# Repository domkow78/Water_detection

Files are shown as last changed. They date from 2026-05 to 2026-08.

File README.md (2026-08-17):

# Water Detection

Repozytorium zawiera projekt systemu detekcji obecności magnesu i sterowania przekaźnikami dla różnych typów czujników wykorzystywanych w układzie wodnym.

## Cel projektu

Głównym celem jest monitorowanie stanu czujników, interpretacja sygnałów z wejść analogowych oraz sterowanie przekaźnikami w zależności od wykrycia obecności magnesu lub zmiany poziomu cieczy.

## Zawartość repozytorium

### Dokumentacja
- [APS11450_Program_Description.md](APS11450_Program_Description.md) — opis działania programu dla czujnika APS11450.
- [TLE4946_Program_Description.md](TLE4946_Program_Description.md) — opis działania programu dla czujnika TLE4946.
- [TMAG5124_Program_Description.md](TMAG5124_Program_Description.md) — opis działania programu dla czujnika TMAG5124B.
- [ReedSwitch_Program_Description.md](ReedSwitch_Program_Description.md) — opis działania programu dla czujnika Reed Switch.
- [APS11450.md](APS11450.md), [TLE4946.md](TLE4946.md), [TMAG5124B.md](TMAG5124B.md) — dokumentacja techniczna sensorów.

### Katalog src
W katalogu [src](src) znajdują się programy Arduino dla poszczególnych czujników:
- [src/Detector_APS11450](src/Detector_APS11450)
- [src/Detector_TLE4946](src/Detector_TLE4946)
- [src/Detector_TMAG5124](src/Detector_TMAG5124)
- [src/Detector_ReedSwitch](src/Detector_ReedSwitch)

Każdy program realizuje własną logikę detekcji i sterowania, dostosowaną do konkretnego typu czujnika.

### Katalog doc
W katalogu [doc](doc) znajduje się dokumentacja projektowa, modele 3D, schematy i pliki PCB związane z konstrukcją urządzenia.

### Katalog tests
Katalog [tests](tests) jest przeznaczony na testy i sprawdzenia funkcjonalne projektu.

## Wspierane typy czujników

- APS11450 — czujnik Halla używany do detekcji poziomu cieczy z diagnostyką.
- TLE4946 — czujnik Halla typu latch.
- TMAG5124B — czujnik prądowy z detekcją obecności magnesu.
- Reed Switch — czujnik binarny z połączeniem typu NO/NC zależnym od obecności magnesu.

## Główne funkcje systemu

- odczyt ADC z wejść czujników,
- konwersja sygnału na napięcie i prawidłową interpretację,
- histereza i filtracja stanów przejściowych,
- sterowanie przekaźnikami,
- logowanie danych przez UART,
- wizualizacja stanu na wyświetlaczu OLED.

## Narzędzia i platforma

Projekt jest realizowany w środowisku Arduino dla mikrokontrolerów AVR, z wykorzystaniem:
- biblioteki Arduino Core,
- wyświetlacza OLED SSD1306,
- obsługi watchdoga i ADC,
- przekaźników sterujących pracą układu.

## Krótka instrukcja

1. Otwórz odpowiedni plik programu z katalogu [src](src).
2. Wgraj skrypt na mikrokontroler.
3. Sprawdź działanie za pomocą monitora szeregowego i wyświetlacza OLED.
4. W razie potrzeby korzystaj z opisów w dokumentacji programowej.

## Uwagi

Repozytorium zawiera wersje projektowe dla różnych czujników i różnych podejść do detekcji, dlatego ważne jest dobieranie odpowiedniego programu do konkretnych komponentów zastosowanych w układzie.

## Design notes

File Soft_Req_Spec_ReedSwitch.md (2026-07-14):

# Sterownik poziomu wody oparty o kontaktrony (Reed Switch)

_Specyfikacja funkcjonalna_

## 1. Cel projektu

Celem projektu jest realizacja układu pomiaru poziomu cieczy przy użyciu trzech kontaktronów oraz pływaka z magnesem.

Dla zewnętrznego sterownika aplikacja ma zachowywać się identycznie jak klasyczny układ trzech elektrod zanurzeniowych.

---

## 2. Architektura

```text
Reed Switch x3
	│
	▼
Sensor Manager
	│
	▼
Level Resolver
	│
	▼
Relay Manager
	│
	▼
Sterownik zewnętrzny
```

### Sensor Manager

Odpowiada wyłącznie za warstwę sprzętową:

- odczyt wejść LOW/HIGH/SAFETY,
- podstawową filtrację drgań styków (debounce),
- publikację aktualnych stanów wejść.

Wyjście:

```text
SensorState
{
    low
    high
    safety
}
```

Sensor Manager nigdy nie interpretuje poziomu cieczy.

---

### Level Resolver

Jedyny moduł posiadający pamięć stanu.

Odpowiada za:

- określenie poziomu,
- inicjalizację po restarcie,
- filtrowanie stanów przejściowych,
- wykrywanie kierunku ruchu pływaka,
- emulację elektrod.

---

### Relay Manager

Wyłącznie mapuje poziom logiczny na wyjścia przekaźników.

---

## 3. Poziomy systemu

| Stan | R1 | R2 | R3 |
| --- | --- | --- | --- |
| EMPTY | 0 | 0 | 0 |
| LEVEL1 | 1 | 0 | 0 |
| LEVEL2 | 1 | 1 | 0 |
| LEVEL3 | 1 | 1 | 1 |

---

## 4. Wirtualne elektrody

| Poziom | E1 | E2 | E3 |
| --- | --- | --- | --- |
| EMPTY | 0 | 0 | 0 |
| LEVEL1 | 1 | 0 | 0 |
| LEVEL2 | 1 | 1 | 0 |
| LEVEL3 | 1 | 1 | 1 |

Relay Manager korzysta wyłącznie z E1-E3.

---

## 5. Automat stanów

```text
UNKNOWN
   │
   ▼
EMPTY <-> LEVEL1 <-> LEVEL2 <-> LEVEL3
```

Zmiany stanu są możliwe wyłącznie między sąsiednimi poziomami.

---

## 6. Restart

Po restarcie:

1. Sensor Manager rozpoczyna odczyt wejść i debounce.
2. Przez określony czas zbierane są próbki stanu wejść.
3. Level Resolver wybiera najbardziej prawdopodobny poziom startowy.
4. Aktualizowane są E1-E3.
5. Relay Manager ustawia przekaźniki zgodnie z wybranym poziomem.

Do czasu zakończenia inicjalizacji zaleca się utrzymanie poprzedniego stanu wyjść.

---

## 7. Stany przejściowe

Podczas ruchu pływaka mogą występować chwilowe kombinacje stanów wejść, które nie odpowiadają stabilnemu poziomowi.

Takie stany nie powodują natychmiastowej zmiany poziomu.

Level Resolver:

- wykorzystuje poprzedni poziom,
- oczekuje stabilizacji wejść przez zdefiniowany czas,
- dopiero wtedy zatwierdza nowy poziom.

---

## 8. Tabela przejść

| Aktualny stan | Potwierdzone zdarzenie | Nowy stan | Akcja |
| --- | --- | --- | --- |
| UNKNOWN | INIT_COMPLETE + EMPTY | EMPTY | R=000 |
| UNKNOWN | INIT_COMPLETE + LEVEL1 | LEVEL1 | R=100 |
| UNKNOWN | INIT_COMPLETE + LEVEL2 | LEVEL2 | R=110 |
| UNKNOWN | INIT_COMPLETE + LEVEL3 | LEVEL3 | R=111 |
| EMPTY | LEVEL1 potwierdzony | LEVEL1 | Włącz R1 |
| LEVEL1 | LEVEL2 potwierdzony | LEVEL2 | Włącz R2 |
| LEVEL2 | LEVEL3 potwierdzony | LEVEL3 | Włącz R3 |
| LEVEL3 | LEVEL2 potwierdzony | LEVEL2 | Wyłącz R3 |
| LEVEL2 | LEVEL1 potwierdzony | LEVEL1 | Wyłącz R2 |
| LEVEL1 | EMPTY potwierdzony | EMPTY | Wyłącz R1 |

---

## 9. Kombinacje niestabilne

Surowe odczyty:

```text
010
001
101
011
```

traktowane są jako stany przejściowe i nie powodują bezpośredniej zmiany poziomu.

Ich interpretacja zależy wyłącznie od historii stanów oraz czasu stabilizacji.

---

## 10. Zasady implementacyjne

- Przekaźniki nigdy nie są sterowane bezpośrednio z kontaktronów.
- Jedynym źródłem informacji o poziomie jest Level Resolver.
- Sensor Manager nie zawiera logiki procesu.
- Relay Manager nie odczytuje czujników.
- Wszystkie zmiany poziomu powinny być logowane.
- System musi być odporny na restart oraz chwilowe stany przejściowe.

---

## 11. Skalowalność

Dodanie kolejnych poziomów wymaga:

- dodania czujnika,
- rozszerzenia konfiguracji Level Resolver,
- rozszerzenia tabeli przejść.

Pozostałe moduły pozostają bez zmian.

---

## 12. Główna zasada projektowa

Kontaktrony nie sterują bezpośrednio przekaźnikami.

Kontaktrony dostarczają wyłącznie sygnały wejściowe.

Level Resolver przekształca sygnały w logiczny stan poziomu.

Relay Manager generuje sygnały identyczne z klasycznym układem elektrod zanurzeniowych.

Dzięki temu aplikacja zachowuje zgodność funkcjonalną z układem elektrodowym i zapewnia stabilną pracę podczas ruchu pływaka oraz po restarcie.

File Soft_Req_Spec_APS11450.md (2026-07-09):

# Sterownik poziomu wody oparty o APS11450

_Specyfikacja funkcjonalna_

## 1. Cel projektu

Celem projektu jest zastąpienie klasycznego układu elektrodowego układem wykorzystującym trzy czujniki Halla APS11450 oraz pływak z magnesem.

Dla zewnętrznego sterownika aplikacja ma zachowywać się identycznie jak trzy elektrody zanurzeniowe.

---

## 2. Architektura

```text
APS11450 x3
     │
     ▼
Sensor Manager
     │
     ▼
Level Resolver
     │
     ▼
Relay Manager
     │
     ▼
Sterownik zewnętrzny
```

### Sensor Manager

Odpowiada wyłącznie za sprzęt:

- odczyt wejść LOW/HIGH/SAFETY,
- odczyt ADC (diagnostyka APS11450),
- wykrywanie Internal Fault,
- wykrywanie External Fault.

Wyjście:

```text
SensorState
{
    low
    high
    safety
    lowFault
    highFault
    safetyFault
}
```

Nigdy nie interpretuje poziomu cieczy.

---

### Level Resolver

Jedyny moduł posiadający pamięć stanu.

Odpowiada za:

- określenie poziomu,
- inicjalizację po restarcie,
- filtrowanie stanów przejściowych,
- wykrywanie kierunku ruchu,
- diagnostykę logiczną,
- emulację elektrod.

---

### Relay Manager

Wyłącznie mapuje poziom na wyjścia przekaźników.

---

## 3. Poziomy systemu

| Stan | R1 | R2 | R3 |
| --- | --- | --- | --- |
| EMPTY | 0 | 0 | 0 |
| LEVEL1 | 1 | 0 | 0 |
| LEVEL2 | 1 | 1 | 0 |
| LEVEL3 | 1 | 1 | 1 |
| FAULT | zgodnie z konfiguracją bezpieczeństwa | | |

---

## 4. Wirtualne elektrody

| Poziom | E1 | E2 | E3 |
| --- | --- | --- | --- |
| EMPTY | 0 | 0 | 0 |
| LEVEL1 | 1 | 0 | 0 |
| LEVEL2 | 1 | 1 | 0 |
| LEVEL3 | 1 | 1 | 1 |

Relay Manager korzysta wyłącznie z E1-E3.

---

## 5. Automat stanów

```text
UNKNOWN
   │
   ▼
EMPTY <-> LEVEL1 <-> LEVEL2 <-> LEVEL3

Każdy stan -> FAULT
FAULT -> UNKNOWN
```

---

## 6. Restart

Po restarcie:

1. Sensor Manager wykonuje diagnostykę.
2. Przez określony czas zbierane są próbki.
3. Level Resolver wybiera najbardziej prawdopodobny poziom.
4. Aktualizowane są E1-E3.
5. Relay Manager ustawia przekaźniki.

Do czasu zakończenia inicjalizacji zaleca się utrzymanie poprzedniego stanu wyjść.

---

## 7. Stany przejściowe

Podczas przejazdu magnesu mogą pojawić się kombinacje nieodpowiadające rzeczywistemu poziomowi.

Nie powodują one natychmiastowej zmiany poziomu.

Level Resolver:

- wykorzystuje poprzedni poziom,
- oczekuje stabilizacji,
- dopiero wtedy zatwierdza nowy poziom.

---

## 8. Diagnostyka

### Sprzętowa

- Internal Fault APS11450
- External Fault APS11450
- błędy ADC

### Logiczna

- niedozwolona sekwencja,
- przeskok poziomu,
- zbyt długi stan przejściowy,
- utrata synchronizacji,
- niespójne stany.

---

## 9. Tabela przejść

| Aktualny stan | Potwierdzone zdarzenie | Nowy stan | Akcja |
| --- | --- | --- | --- |
| UNKNOWN | INIT_COMPLETE + EMPTY | EMPTY | R=000 |
| UNKNOWN | INIT_COMPLETE + LEVEL1 | LEVEL1 | R=100 |
| UNKNOWN | INIT_COMPLETE + LEVEL2 | LEVEL2 | R=110 |
| UNKNOWN | INIT_COMPLETE + LEVEL3 | LEVEL3 | R=111 |
| EMPTY | LEVEL1 potwierdzony | LEVEL1 | Włącz R1 |
| LEVEL1 | LEVEL2 potwierdzony | LEVEL2 | Włącz R2 |
| LEVEL2 | LEVEL3 potwierdzony | LEVEL3 | Włącz R3 |
| LEVEL3 | LEVEL2 potwierdzony | LEVEL2 | Wyłącz R3 |
| LEVEL2 | LEVEL1 potwierdzony | LEVEL1 | Wyłącz R2 |
| LEVEL1 | EMPTY potwierdzony | EMPTY | Wyłącz R1 |
| Dowolny | Internal/External Fault | FAULT | Alarm |

---

## 10. Niedozwolone kombinacje

Surowe odczyty:

```text
010
001
101
011
```

nie powodują automatycznie zmiany poziomu.

Mogą oznaczać:

- ruch pływaka,
- restart,
- uszkodzenie czujnika,
- uszkodzenie okablowania.

Ich interpretacja zależy od historii i diagnostyki.

---

## 11. Zasady implementacyjne

- Przekaźniki nigdy nie są sterowane bezpośrednio z czujników.
- Jedynym źródłem informacji o poziomie jest Level Resolver.
- Sensor Manager nie zna logiki procesu.
- Relay Manager nie odczytuje czujników.
- Wszystkie zmiany poziomu są logowane.
- Wszystkie błędy posiadają własny kod diagnostyczny.
- System musi być odporny na restart oraz stany przejściowe.

---

## 12. Skalowalność

Dodanie kolejnych poziomów wymaga:

- dodania czujnika,
- rozszerzenia konfiguracji Level Resolver,
- rozszerzenia tabeli przejść.

Pozostałe moduły pozostają bez zmian.

---

## 13. Główna zasada projektowa

Czujniki APS11450 nie sterują przekaźnikami.

Czujniki dostarczają wyłącznie dane pomiarowe.

Level Resolver przekształca dane w logiczny stan poziomu.

Relay Manager generuje sygnały identyczne z klasycznym układem elektrodowym.

Dzięki temu aplikacja jest odporna na:

- przejazd magnesu pomiędzy czujnikami,
- restart urządzenia,
- błędy pojedynczych czujników,
- zmianę technologii czujników w przyszłości.

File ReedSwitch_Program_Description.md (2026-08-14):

# Opis działania programu dla Reed Switch

## 1. Cel programu

Program sprawdza trzy kanały Reed Switch:
- `LOW`
- `HIGH`
- `SAFE`

Dla każdego kanału odczytuje stan wejścia i steruje odpowiadającym mu przekaźnikiem.

Zasada działania jest prosta i binarna:
- reed zwarty przez magnes = stan aktywny
- reed rozwarty = stan nieaktywny
- przekaźnik odzwierciedla stan danego czujnika

Nie ma tutaj mapowania poziomu na inny stan, nie ma automatu stanu i nie ma rozbudowanej diagnostyki błędów.

---

## 2. Wejścia i wyjścia

### 2.1. Wejścia

Wszystkie wejścia są ustawione jako `INPUT_PULLUP`:
- `REED_LOW_PIN = 2`
- `REED_HIGH_PIN = 3`
- `REED_SAFE_PIN = 4`

Dla takiego podłączenia:
- stan aktywny = `LOW` (kontakt zwarty, magnes w pobliżu, wejście podłączone do GND)
- stan nieaktywny = `HIGH` (kontakt rozwarty, wejście podciągnięte do VCC)

### 2.2. Wyjścia

Przekaźniki są sterowane osobno dla każdego kanału:
- `RELAY_LOW_PIN = A0`
- `RELAY_HIGH_PIN = A1`
- `RELAY_SAFE_PIN = A2`

Każdy przekaźnik ma odpowiadać stanowi swojego reed switcha.

---

## 3. Logika działania

Program odczytuje napięcie na każdym wejściu Reed Switch i interpretuje je jako dwa stany:

- napięcie bliskie 0 V → reed zwarty → przekaźnik ON
- napięcie bliskie VCC → reed rozwarty → przekaźnik OFF

To jest czysta logika binarna. Każdy kanał działa niezależnie.

---

## 4. Histereza

Aby uniknąć migania przy przejściach, program stosuje progi histerezy:

- `REED_ACTIVE_V = 1.0 V`
- `REED_RELEASED_V = 2.5 V`

Dla danego kanału:
- jeżeli stan jest nieaktywny i napięcie spadnie poniżej 1,0 V, kanał przechodzi do aktywnego,
- jeżeli stan jest aktywny i napięcie wzrośnie powyżej 2,5 V, kanał przechodzi do nieaktywnego,
- w pozostałych przypadkach stan zostaje bez zmian.

Dzięki temu krótkie oscylacje napięcia nie powodują niepotrzebnych przełączeń przekaźników.

---

## 5. Odczyt analogowy i VCC

Program mierzy napięcie na wejściach analogowo, ale robi to wyłącznie po to, aby odczytać rzeczywisty poziom sygnału i porównać go z progami histerezy. Nie ma osobnej funkcji diagnostycznej typu `OPEN`/`SHORT`.

Wartość `Vcc` jest odczytywana przez funkcję `readVcc()` i wykorzystywana do przeliczenia surowego odczytu ADC na napięcie w woltoch.

W praktyce oznacza to, że program ma dane do logowania i wizualizacji, ale nie rozpoznaje specjalnych stanów awarii, ponieważ czujnik Reed w tym układzie ma tylko dwa sensowne stany: zamknięty lub rozwarty.

---

## 6. Co dzieje się w `setup()`

W funkcji `setup()` program:
1. inicjalizuje port szeregowy,
2. ustawia wejścia Reed Switch jako `INPUT_PULLUP`,
3. ustawia wszystkie przekaźniki jako `OUTPUT`,
4. wyłącza przekaźniki na starcie,
5. inicjalizuje OLED,
6. odczytuje napięcie zasilania `Vcc`,
7. odczytuje początkowe stany wejść,
8. ustawia przekaźniki zgodnie z aktualnym stanem każdego kanału,
9. uruchamia watchdog.

---

## 7. Co dzieje się w `loop()`

W każdej iteracji programu:
1. odczytywane są wartości ADC dla `LOW`, `HIGH` i `SAFE`,
2. sygnały są zamieniane na napięcie w woltoch,
3. stosowana jest histereza dla każdego kanału,
4. przekaźniki otrzymują stan zgodny z wejściem,
5. dane są wysyłane do `Serial Monitor` i ekranu OLED.

---

## 8. Podsumowanie

Program dla Reed Switch działa w modelu 3 niezależnych kanałów binarnych:

- `LOW`: reed zwarty → LOW → przekaźnik ON
- `HIGH`: reed zwarty → LOW → przekaźnik ON
- `SAFE`: reed zwarty → LOW → przekaźnik ON

Przy rozwartym kontakcie:

- `HIGH`/`LOW`/`SAFE` = `HIGH` → przekaźnik OFF

W tym układzie największe znaczenie ma poprawna interpretacja napięcia i histereza. Nie ma rozbudowanej diagnostyki, bo czujnik ma tylko 2 realne stany logiczne: zamknięty i rozwarty.

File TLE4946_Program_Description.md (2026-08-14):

# Opis działania programu dla TLE4946

## 1. Cel programu

Program monitoruje trzy kanały czujników TLE4946 i na ich podstawie steruje trzema przekaźnikami. Każdy kanał jest odczytywany jako napięcie analogowe pochodzące z czujnika Halla, a następnie analizowany przez program z wykorzystaniem progów histerezy.

Głównym celem jest wykrywanie zmiany stanu czujnika w zależności od poziomu pola magnetycznego i utrzymanie stabilnych stanów logicznych w obecności zakłóceń, niewielkich zmian napięcia oraz szumu pomiarowego.

---

## 2. Założenia projektowe

### 2.1. Obwód pomiarowy

Każdy czujnik TLE4946 jest podłączony do wejścia ADC mikrokontrolera:
- HALL_LOW_PIN = A3
- HALL_HIGH_PIN = A6
- HALL_SAFE_PIN = A7

Napięcie z czujnika jest mierzone względem aktualnego napięcia zasilania układu.

### 2.2. Przekaźniki

Sterowanie przekaźnikami odbywa się poprzez wyjścia cyfrowe:
- RELAY_LOW_PIN = A0
- RELAY_HIGH_PIN = A1
- RELAY_SAFE_PIN = A2

Przekaźniki są aktywowane lub wyłączane na podstawie stanu odczytu z odpowiedniego czujnika.

---

## 3. Odczyt z ADC i uśrednianie

Każdy kanał odczytywany jest z wejścia ADC mikrokontrolera. W celu ograniczenia wpływu szumu i chwilowych niestabilności sygnału program wykonuje odczyty stabilizowane.

W praktyce funkcja `readADCStable()` działa w następujący sposób:
1. wykonuje pierwszy pomiar dla danego wejścia
2. odczekuje krótko (20 µs)
3. wykonuje kolejny pomiar
4. zwraca wartość z drugiego odczytu

To pozwala zmniejszyć błędy wynikające z nieustalonego stanu wejścia ADC lub krótkotrwałych zakłóceń.

Po odczycie wartość ADC jest zamieniana na napięcie:

V = (ADC / 1023) × VCC

Dzięki temu napięcia z czujników są skalowane do rzeczywistego napięcia zasilania systemu, a nie przyjmowane na sztywno jako 5 V.

Dodatkowo w tej wersji program wykonuje średniowanie z 8 próbek dla każdego kanału, co zwiększa odporność na drobne fluktuacje sygnału.

---

## 4. Weryfikacja VCC

Program mierzy napięcie zasilania mikrokontrolera w funkcji `readVcc()`. Jest to ważny element, ponieważ sygnał z czujnika musi być przeliczony względem aktualnego VCC.

Wewnętrzny mechanizm AVR ustawia wejście ADC do pracy z referencją wewnętrzną, po czym odczytuje wynik. Na podstawie tego wyniku obliczana jest wartość zasilania w milivoltach.

Równanie zastosowane w programie:

VCC = 1125300 / ADC

Po przeliczeniu otrzymane napięcie jest przekazywane dalej do funkcji konwertującej ADC na napięcie:

V = (ADC / 1023) × VCC

Dzięki temu pomiar ma większą dokładność i jest odporny na zmiany napięcia zasilania.

---

## 5. Logika detekcji i histereza

Po odczycie napięcia z każdego kanału program stosuje funkcję `applyHysteresis()`. Jest to podstawowy mechanizm stabilizacji działania układu.

Progi w tej wersji:
- LOW_THRESHOLD_V = 0.3 V
- HIGH_THRESHOLD_V = 1.5 V

Logika:
- jeżeli stan jest wyłączony i napięcie przekroczy 1,5 V, stan zmienia się na włączony
- jeżeli stan jest włączony i napięcie spadnie poniżej 0,3 V, stan zmienia się na wyłączony
- w pozostałych przypadkach stan pozostaje bez zmian

To zapobiega miganiu stanu przy napięciach zbliżonych do progu i poprawia stabilność pracy.

W praktyce program traktuje czujnik jako aktywny, gdy jego napięcie rośnie powyżej progu aktywacji. Gdy napięcie spadnie poniżej progu wyłączenia, czujnik wraca do stanu nieaktywnego.

To jest typowa logika dla czujnika Halla pracującego jako źródło napięcia analogowego, który reaguje na obecność lub brak pola magnetycznego.

---

## 6. Inicjalizacja i start systemu

W funkcji `setup()` program wykonuje następujące czynności:
1. wyłącza watchdog
2. inicjalizuje port szeregowy
3. konfiguruje piny przekaźników jako wyjścia
4. ustawia przekaźniki w stanie wyłączonym
5. inicjalizuje wyświetlacz OLED
6. odczytuje VCC
7. odczytuje napięcia z trzech czujników
8. przydziela początkowe stany logiczne na podstawie progu aktywacji
9. ustawia przekaźniki zgodnie z odczytem
10. uruchamia watchdog

Warto zaznaczyć, że przy starcie nie jest wykonywana żadna specjalna procedura kalibracji; sygnał jest po prostu odczytywany na bieżąco i oceniany względem progów.

Po starcie wyświetlany jest komunikat startowy oraz wartość VCC.

---

## 7. Pętla główna

W pętli `loop()` program wykonuje następujące czynności cyklicznie:
1. resetuje watchdog
2. odczytuje napięcia z każdego czujnika
3. konwertuje je na napięcia względem VCC
4. stosuje histerezę dla każdego kanału
5. ustawia stany przekaźników
6. raz na 500 ms wysyła dane do Serial Monitor
7. raz na 500 ms odświeża ekran OLED

---

## 8. Diagnostyka i prezentacja danych

Program wysyła do portu szeregowego dane w postaci:
- napięcie LOW
- napięcie HIGH
- napięcie SAFE
- stany przekaźników

Na wyświetlaczu OLED pokazuje:
- nazwy kanałów
- wartości napięć
- stany przekaźników

Dzięki temu możliwe jest sprawdzenie, czy czujniki pracują poprawnie, czy sygnał jest stabilny i czy przekaźniki odpowiednio reagują na zmiany poziomu.

---

## 9. Podsumowanie

Program dla TLE4946 działa jako system monitorujący trzy kanały czujników Hall z wykorzystaniem analogowych odczytów napięcia. W praktyce program:

- odczytuje napięcia z czujników,
- skaluję je względem aktualnego VCC,
- filtruje zakłócenia i niestabilności,
- stosuje histerezę,
- steruje przekaźnikami w zależności od stanu czujników.

Dzięki temu układ jest odporny na krótkotrwałe niestabilności sygnału, a stan przekaźników pozostaje stabilny nawet przy niewielkich wahaniach napięcia.

To sprawia, że system jest odpowiedni do prostego monitorowania poziomu pola magnetycznego oraz do realizacji prostego sterowania wyjściami na podstawie odczytu z czujników hallowskich.

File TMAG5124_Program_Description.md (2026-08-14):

# Opis działania programu dla TMAG5124

## 1. Cel programu

Program monitoruje trzy kanały czujników TMAG5124B zintegrowanych w układzie detekcji obecności magnesu. Każdy kanał jest odczytywany poprzez napięcie powstające na rezystorze pomiarowym 220 Ω. Na podstawie tego napięcia mikrokontroler decyduje, czy magnes jest obecny, czy nie, a następnie steruje odpowiednim przekaźnikiem.

Czujnik pracuje w trybie prądowym:
- przy braku magnesu: około 14,5 mA
- przy obecności magnesu: około 3,5 mA

Ponieważ prąd płynie przez rezystor 220 Ω, zmiana prądu powoduje zmianę napięcia:
- brak magnesu: około 3,19 V
- magnes obecny: około 0,77 V

W układzie założono, że przekaźnik ma być aktywny wyłącznie wtedy, gdy zostanie wykryty magnes.

---

## 2. Założenia projektowe

### 2.1. Obwód pomiarowy

Każdy czujnik TMAG5124B jest podłączony do układu z rezystorem pomiarowym 220 Ω. Na tym rezystorze powstaje napięcie proporcjonalne do prądu czujnika.

Napięcie jest mierzone przez wejścia ADC mikrokontrolera:
- SENSOR_LOW_PIN = A3
- SENSOR_HIGH_PIN = A6
- SENSOR_SAFE_PIN = A7

### 2.2. Przekaźniki

Sterowanie przekaźnikami odbywa się poprzez wyjścia cyfrowe:
- RELAY_LOW_PIN = A0
- RELAY_HIGH_PIN = A1
- RELAY_SAFE_PIN = A2

Przekaźniki są przełączane tylko na podstawie odczytu z czujników, a nie bezpośrednio przez sam czujnik.

---

## 3. Odczyt z ADC i uśrednianie

Każdy kanał jest odczytywany przez wejście ADC mikrokontrolera. Aby zmniejszyć wpływ szumu, zakłóceń i krótkich fluktuacji napięcia, program wykonuje uśrednianie kilku kolejnych odczytów dla każdego wejścia.

W praktyce funkcja odczytu działa w następujący sposób:
1. pobiera odczyt z wejścia ADC
2. wykonuje dodatkowe 7 odczytów w krótkich odstępach czasowych
3. sumuje wszystkie wyniki
4. dzieli sumę przez liczbę próbek
5. otrzymuje średnią wartość, która jest dalej przeliczana na napięcie

Taki mechanizm pozwala ograniczyć wpływ krótkotrwałych zmian sygnału i poprawia stabilność działania czujników oraz przekaźników.

Po uśrednieniu wartość ADC jest zamieniana na napięcie zgodnie z zależnością:

V = (ADC / 1023) × VCC

Następnie otrzymane napięcie jest analizowane przez logikę detekcji magnesu i diagnostyki.

### 3.1. Weryfikacja VCC

Program weryfikuje napięcie zasilania mikrokontrolera w funkcji `readVcc()`. Wewnętrzny mechanizm AVR ustawia wejście ADC do pomiaru napięcia odniesienia, a następnie odczytuje wynik z rejestru `ADC`.

Dzięki temu system nie zakłada sztywnego napięcia 5 V, tylko rzeczywiście odczytuje aktualne VCC. Wynik jest przeliczany według zależności:

VCC = 1125300 / ADC

Wartość ta jest wyrażona w milivoltach, a następnie zamieniana na wolty przez podzielenie przez 1000.

Dzięki temu każda wartość ADC jest skalowana do aktualnego napięcia zasilania układu, co poprawia dokładność pomiaru napięcia na rezystorze 220 Ω.

---

## 4. Logika detekcji magnesu

Program odczytuje napięcie z każdego kanału, a następnie stosuje histerezę:
- kiedy stan jest nieaktywny i napięcie spadnie poniżej 1,5 V, stan przechodzi do aktywnego
- kiedy stan jest aktywny i napięcie wzrośnie powyżej 2,6 V, stan przechodzi do nieaktywnego

Dzięki temu układ nie „miga” przy wartościach napięcia bliskich progowi.

### 3.1. Praktyczna interpretacja

- brak magnesu → napięcie ~3,19 V → stan nieaktywny
- magnes obecny → napięcie ~0,77 V → stan aktywny

W praktyce oznacza to, że przy obecności magnesu przekaźnik zostaje włączony.

---

## 5. Diagnostyka czujników

Dodatkowo program rozpoznaje stany awaryjne, które nie są poprawnym wykryciem magnesu:

### 5.1. Brak prądu / przerwa obwodu

Jeżeli napięcie na rezystorze jest poniżej 0,25 V, program klasyfikuje czujnik jako:
- OPEN

To oznacza brak prądu lub przerwę w obwodzie. W takim stanie przekaźnik jest wyłączany, ponieważ nie ma prawidłowego sygnału z czujnika.

### 5.2. Prąd znacznie powyżej normy

Jeżeli napięcie przekroczy 4,2 V, program klasyfikuje czujnik jako:
- OVR (over current)

To oznacza, że czujnik pobiera prąd znacznie większy niż w normalnym zakresie pracy. Taki stan jest traktowany jako awaria i też powoduje wyłączenie przekaźnika.

### 5.3. Stan prawidłowy

Dla napięcia w normalnym zakresie program przyjmuje:
- OK

---

## 6. Sterowanie przekaźnikami

Po przetworzeniu odczytu dla każdego kanału program wykonuje następujące kroki:
1. odczyt napięcia z czujnika
2. rozpoznanie diagnostyki (OK / OPEN / OVR)
3. zastosowanie histerezy przy poprawnym odczycie
4. ustawienie stanu przekaźnika
5. zapisanie stanu do wyjścia cyfrowego

Przekaźnik jest aktywowany tylko wtedy, gdy:
- czujnik jest w stanie poprawnym,
- magnes został wykryty,
- napięcie mieszczą się w zakresie aktywacji.

W przypadku stanu OPEN lub OVR przekaźnik jest wymuszony do stanu wyłączonego.

---

## 7. Wyświetlacz OLED

Program wyświetla dane na ekranie SSD1306:
- napięcie każdego czujnika w V
- status diagnostyczny każdego czujnika (OK / OPEN / OVR)
- stan przekaźników

Dodatkowo wyświetlany jest komunikat startowy oraz aktualna wartość Vcc.

---

## 8. Port szeregowy

Program wysyła dane do Serial Monitor co 500 ms. W raporcie zawarte są:
- napięcia z trzech czujników
- ich status diagnostyczny
- stany przekaźników

Dzięki temu możliwe jest łatwe monitorowanie działania układu podczas testów i kalibracji.

---

## 9. Watchdog

Program włącza watchdog o interwale 1 s. Dzięki temu układ jest chroniony przed zawieszeniem w pętli działania i automatycznie resetuje się w przypadku zablokowania programu.

---

## 10. Podsumowanie

Program działa zgodnie z następującą zasadą:

- TMAG5124 mierzy prąd zależny od obecności magnesu
- prąd jest zamieniany na napięcie na rezystorze 220 Ω
- mikrokontroler interpretuje to napięcie
- jeżeli magnes jest obecny, przekaźnik jest włączany
- jeżeli brak prądu lub prąd jest zbyt wysoki, stan jest uznawany za awarię i przekaźnik jest wyłączany

To zapewnia stabilną pracę, ochronę przed fałszywym załączeniem oraz diagnostykę stanu czujników.

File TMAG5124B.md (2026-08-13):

# TMAG5124B -- Uwagi projektowe i uzupełnienia

## 1. Warianty serii TMAG512x

Opis dotyczy wariantu **TMAG5124B**, w którym:

-   **magnes blisko czujnika** → pobór prądu około **3,5 mA**
-   **magnes daleko od czujnika** → pobór prądu około **14,5 mA**

Warto pamiętać, że rodzina TMAG512x zawiera również inne wersje, w
których logika przełączania może być odwrotna. Dlatego zawsze należy
sprawdzić dokumentację konkretnego wariantu.

------------------------------------------------------------------------

## 2. Progi przełączania

W dokumentacji najczęściej podawane są wartości typowe:

-   **BOP (Point of Operation)** ≈ 6 mT
-   **BRP (Point of Release)** ≈ 3 mT

Są to wartości **typowe**, a nie gwarantowane.

Projektując urządzenie przemysłowe należy uwzględnić również wartości
minimalne i maksymalne podane w dokumentacji producenta.

------------------------------------------------------------------------

## 3. Dobór rezystora pomiarowego

Przykład dla rezystora **100 Ω**:

  Stan                    Prąd   Napięcie
  ------------------ --------- ----------
  Magnes obecny         3,5 mA     0,35 V
  Magnes nieobecny     14,5 mA     1,45 V

Różnica napięć wynosi **1,10 V**, co zapewnia bardzo pewny odczyt.

### Uwaga

Rezystor pomiarowy nie może mieć zbyt dużej wartości.

Przykład dla **470 Ω**:

-   3,5 mA → 1,65 V
-   14,5 mA → 6,82 V

Przy zasilaniu 5 V drugi stan nie będzie możliwy do osiągnięcia,
ponieważ zabraknie napięcia na sam czujnik.

Rezystor należy dobrać tak, aby przy maksymalnym prądzie czujnik nadal
pracował w dopuszczalnym zakresie napięcia zasilania.

------------------------------------------------------------------------

## 4. Odczyt sygnału

Do odczytu nie jest wymagany przetwornik ADC.

Ponieważ występują jedynie dwa poziomy prądu, można wykorzystać:

-   komparator,
-   wejście z histerezą (Schmitt Trigger),
-   prosty tranzystor,
-   wejście cyfrowe mikrokontrolera.

ADC jest potrzebny jedynie wtedy, gdy planowana jest diagnostyka lub
monitorowanie wartości prądu.

------------------------------------------------------------------------

## 5. Diagnostyka przewodów

Pętla prądowa umożliwia wykrywanie uszkodzeń instalacji.

Najbardziej typowe przypadki:

-   **0 mA** -- przerwa przewodu,
-   **wartość spoza prawidłowych poziomów prądu** -- możliwe uszkodzenie
    przewodu lub zwarcie.

Nie należy zakładać, że każde zwarcie spowoduje wzrost prądu powyżej
14,5 mA, ponieważ zależy to od miejsca zwarcia i sposobu zasilania.

------------------------------------------------------------------------

## 6. Praca na długich przewodach

Jedną z największych zalet interfejsu prądowego jest odporność na
długość przewodu.

Przykład:

-   rezystancja przewodu: około 1 Ω,
-   prąd: 14,5 mA,

spadek napięcia:

14,5 mA × 1 Ω = **14,5 mV**

Jest to wartość praktycznie pomijalna.

------------------------------------------------------------------------

## 7. Odporność EMC

Kodowanie informacji za pomocą prądu zapewnia bardzo wysoką odporność na
zakłócenia elektromagnetyczne.

Najważniejsze zalety:

-   odporność na zakłócenia wspólne (Common Mode),
-   niewielki wpływ spadków napięcia na przewodach,
-   możliwość prowadzenia przewodów obok silników, styczników i
    falowników,
-   wysoka niezawodność w środowisku przemysłowym.

------------------------------------------------------------------------

# Rekomendacja projektowa

W aplikacjach wymagających jedynie informacji o stanie czujnika warto
zastosować komparator zamiast przetwornika ADC.

Przykładowy schemat:

``` text
+24 V
  |
TMAG5124B
  |
  +------ wejście komparatora
  |
Rsense
  |
 GND
```

Przykładowy próg komparatora:

**0,9 V**

Odczyt:

-   0,35 V → magnes obecny
-   1,45 V → magnes nieobecny

Takie rozwiązanie jest:

-   prostsze,
-   szybsze,
-   bardziej odporne na zakłócenia,
-   nie wymaga wykonywania pomiarów ADC.

Jeżeli wymagane jest wykrywanie uszkodzeń przewodów, można pozostawić
pomiar ADC lub zastosować dodatkowy układ progowy.

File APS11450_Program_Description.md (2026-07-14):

# Water Detection - APS11450

Dokument opisuje działanie aplikacji [src/Detector_APS11450/Detector_APS11450.ino](src/Detector_APS11450/Detector_APS11450.ino).

## Cel

Aplikacja emuluje klasyczny układ 3 elektrod (E1/E2/E3) przy użyciu 3 czujników Halla APS11450 i pływaka z magnesem.
Wyjścia przekaźników odpowiadają poziomom cieczy:

- EMPTY -> R1=0 R2=0 R3=0
- LEVEL1 -> R1=1 R2=0 R3=0
- LEVEL2 -> R1=1 R2=1 R3=0
- LEVEL3 -> R1=1 R2=1 R3=1
- FAULT -> polityka bezpieczeństwa (w tym projekcie wszystkie ON — stan alarmowy, urządzenie zewnętrzne musi zareagować błędem)

## Architektura logiczna

1. **Sensor Manager**
   - odczyt ADC kanałów LOW/HIGH/SAFE,
   - klasyfikacja sygnału (LOW/HIGH/EXT_FAULT/INT_FAULT),
   - zwraca `SensorState`.
2. **Level Resolver**
   - jedyny moduł z pamięcią stanu,
   - filtruje stany przejściowe,
   - egzekwuje przejścia poziomów,
   - generuje kod diagnostyczny.
3. **Relay Manager**
   - mapuje poziom na E1/E2/E3,
   - steruje przekaźnikami A0/A1/A2.

## Konfiguracja sprzętowa

### Piny

| Sygnał | Pin | Funkcja |
|---|---|---|
| HALL_LOW | A3 | wejście analogowe |
| HALL_HIGH | A6 | wejście analogowe |
| HALL_SAFE | A7 | wejście analogowe |
| RELAY_LOW | A0 | wyjście (R1 / E1) |
| RELAY_HIGH | A1 | wyjście (R2 / E2) |
| RELAY_SAFE | A2 | wyjście (R3 / E3) |
| OLED SDA | A4 | I2C |
| OLED SCL | A5 | I2C |

### OLED / Serial / WDT

- OLED: SSD1306 128x64, adres I2C `0x3C`
- Serial: `115200`
- Watchdog: `WDTO_1S`

## Klasyfikacja napięć APS11450

Próbka jest liczona jako ułamek zasilania: `vFrac = ADC / 1023.0`.

| Zakres VPU | Klasa |
|---|---|
| 0-10% | SIG_EXT_FAULT |
| 10-30% | SIG_LOW |
| 30-70% | SIG_EXT_FAULT |
| 70-90% | SIG_HIGH |
| 90-100% | SIG_INT_FAULT |

Progi w kodzie:
- `VFRAC_EXTLOW_MAX = 0.10`
- `VFRAC_LOW_MAX = 0.30`
- `VFRAC_EXTMID_MAX = 0.70`
- `VFRAC_HIGH_MAX = 0.90`

## Reprezentacja poziomu

Surowy stan bitowy: `raw = (low<<2) | (high<<1) | safety`

Dozwolone kombinacje:
- `000 -> EMPTY`
- `100 -> LEVEL1`
- `110 -> LEVEL2`
- `111 -> LEVEL3`

Niedozwolone kombinacje:
- `010`, `001`, `101`, `011`

Dla niedozwolonych kombinacji poziom nie jest zmieniany (utrzymanie poprzedniego stanu).

## Diagnostyka

### Kody

- `E00` brak błędu
- `E10/E11/E12` Internal Fault (LOW/HIGH/SAFE)
- `E20/E21/E22` External Fault (LOW/HIGH/SAFE)
- `E30` niedozwolona kombinacja raw
- `E31` przeskok poziomu (nie-sąsiedni)
- `E32` zbyt długi stan przejściowy
- `E33` błąd sekwencji (zarezerwowany)
- `E34` utrata synchronizacji (zarezerwowany)

### Reguły resolvera

- błąd czujnika (`*_Fault`) -> natychmiast `FAULT` + kod E1x/E2x,
- po ustąpieniu usterki: `FAULT -> UNKNOWN`,
- zmiana poziomu wymaga stabilności przez `STABLE_MS = 1000 ms`,
- niedozwolone `raw` -> `E30`, a po `TRANSIENT_TIMEOUT_MS = 5000 ms` -> `E32`,
- przeskok o więcej niż 1 poziom -> zatwierdzenie + `E31`.

## Sekwencja startu (`setup`)

1. `wdt_disable()`
2. konfiguracja przekaźników jako OUTPUT i ustawienie OFF,
3. inicjalizacja OLED,
4. pomiar `Vcc` (`readVcc()/1000.0`),
5. inicjalizacja poziomu przez głosowanie większościowe w oknie `INIT_SAMPLE_MS = 1500 ms`,
6. `resolverInit(initLevel)` i ustawienie wyjść,
7. log `INIT_COMPLETE` (Serial + OLED),
8. `wdt_enable(WDTO_1S)`.

## Pętla główna (`loop`)

1. `wdt_reset()`
2. `readSensors()`
3. `resolveLevel()`
4. `applyLevel()`
5. co `logInterval = 500 ms`:
   - log Serial: napięcia, klasy sygnałów, raw, poziom, E1/E2/E3, kod Exx,
   - aktualizacja OLED.

## Funkcje sprzętowe

- `readVcc()` – pomiar Vcc metodą bandgap AVR,
- `readADCStable(pin)` – podwójny odczyt ADC,
- `adcToVoltage(adc)` – konwersja ADC -> V.

## Wymagane biblioteki

- `avr/wdt.h`
- `Wire.h`
- `Adafruit_GFX.h`
- `Adafruit_SSD1306.h`

## Uruchomienie

1. Otwórz [src/Detector_APS11450/Detector_APS11450.ino](src/Detector_APS11450/Detector_APS11450.ino) w Arduino IDE.
2. Wybierz płytkę AVR i port COM.
3. Zainstaluj biblioteki Adafruit GFX i Adafruit SSD1306.
4. Wgraj szkic.
5. Otwórz Serial Monitor (115200).

## Ograniczenia i założenia projektowe

### Fundamentalne założenie: Pływak ZAWSZE musi aktywować co najmniej jeden czujnik

Po restarcie systemu **co najmniej jeden z czujników (LOW, HIGH lub SAFE) musi być aktywny**.

Jeśli to założenie nie jest spełnione, resolver **nie potrafi określić rzeczywistego poziomu cieczy**:

- **Pływak poniżej LOW** → raw = 000 = EMPTY (błęd! poziom nieznany)
- **Pływak powyżej SAFE** → raw = 000 = EMPTY (błęd! przepełnienie niezdetektowane)

#### Konsekwencja

Pływak musi być zawsze w pozycji pomiędzy niżej niż SAFE i wyżej niż LOW. Typowa instalacja:

```
SAFE ←←← górny czujnik (alarm przepełnienia)
HIGH ←←← czujnik środkowy (normalny zakres)
LOW  ←←← dolny czujnik (alarm wyczerpania)
     ↑↑↑ pływak zawsze tu (aktywuje co najmniej jeden)
```

### Brak detekcji przepełnienia

System ma tylko 3 czujniki:
- Nie ma czujnika **powyżej SAFE** → przepełnienie nie jest detektowane,
- pływak powyżej SAFE daje raw = 000, identycznie jak zbiornik pusty.

Aby obsługiwać przepełnienie, trzeba by dodać 4. czujnik (OVERFLOW).

### Czujnik SAFE dla niskich zbiorników

Jeśli zbiornik jest niski (< 30 cm), czujnik SAFE powinien być umieszczony wystarczająco wysoko, aby był aktywny w maksymalnym poziomie, do którego zbiornik może się napełnić. W przeciwnym razie górny poziom LEVEL3 nie będzie nigdy osiągnięty.

## Uwagi

- W VS Code mogą pojawiać się ostrzeżenia includePath dla `avr/wdt.h`; kompilacja docelowo w Arduino IDE.
- Typy (`enum/struct`) są umieszczone przed pierwszą funkcją, aby uniknąć problemu auto-prototypów Arduino.

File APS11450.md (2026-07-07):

# Zasada działania czujnika APS11450

## Cel dokumentu

Dokument opisuje działanie APS11450 z punktu widzenia implementacji oprogramowania i diagnostyki.

## 1. Ogólna zasada działania

APS11450 jest trójprzewodowym planarnym czujnikiem Halla zgodnym z ISO 26262 (SEooC, ASIL B). Czujnik wykrywa obecność pola magnetycznego i udostępnia stan wyjścia oraz informacje diagnostyczne poprzez poziom napięcia wyjściowego.

## 2. Cykl pracy

1. Autodiagnostyka.
2. Pomiar pola magnetycznego.
3. Porównanie z progami BOP i BRP.
4. Aktualizacja wyjścia.
5. Diagnostyka wewnętrzna.
6. Przejście do FAULT w razie błędu.
7. Powtarzanie cyklu.

## 3. Logika magnetyczna

- BOP -- próg przełączenia.
- BRP -- próg powrotu.
- BHYS = BOP - BRP.

Dostępne warianty: Unipolar North, Unipolar South, Omnipolar, Latching.

## 4. Co widzi mikrokontroler

Nie widzi:

- wartości pola,
- odległości od magnesu,
- kierunku ruchu,
- prędkości ruchu.

Widzi:

- VOUT(LOW),
- VOUT(HIGH),
- VOUT(FAULT),
- niepoprawne poziomy napięcia (przy użyciu ADC).

## 5. Poprawne stany wyjścia

| Stan | Typowe napięcie |
| --- | --- |
| VOUT(LOW) | ok. 20% VPU |
| VOUT(HIGH) | ok. 80% VPU |
| VOUT(FAULT) | VPU |

Znaczenie LOW/HIGH zależy od wariantu czujnika i aplikacji.

## 6. Obszary napięć

| Zakres | Znaczenie |
| --- | --- |
| 0-10% VPU | Potencjalna usterka zewnętrzna |
| 10-30% VPU | Poprawny LOW |
| 30-70% VPU | Potencjalna usterka zewnętrzna |
| 70-90% VPU | Poprawny HIGH |
| 90-100% VPU | HIGH lub FAULT zgodnie z dokumentacją |

Każde napięcie poza poprawnym zakresem LOW/HIGH należy traktować jako potencjalną usterkę.

## 7. Diagnostyka

### Wewnętrzna

Monitorowane są:

- element Halla,
- tor analogowy,
- regulator,
- logika cyfrowa,
- pamięć,
- temperatura.

Po wykryciu błędu: VOUT = VPU.

Diagnostyka jest ponawiana co około 2 ms.

### Zewnętrzna

| Usterka | Wynik |
| --- | --- |
| Zwarcie VCC-VOUT | VCC |
| Zwarcie VOUT-GND | GND |
| Zwarcie VCC-GND | VPU |
| Przerwa VCC | VPU |
| Przerwa VOUT | VPU |
| Przerwa GND | VPU |
| Internal Fault | VPU |

## 8. Power-On

Po włączeniu zasilania wyjście pozostaje w stanie VOUT(FAULT) do zakończenia inicjalizacji.

## 9. Maszyna stanów

```text
POWER_ON
   |
   v
NORMAL_LOW <----> NORMAL_HIGH
      ^             |
      |             |
      +----FAULT----+
```

Przejście LOW→HIGH następuje po przekroczeniu BOP. Przejście HIGH→LOW następuje po spadku poniżej BRP. Internal Fault powoduje przejście do FAULT.

## 10. Tabela stanów

| Stan | Warunek | Wyjście |
| --- | --- | --- |
| POWER_ON | Start | VPU |
| NORMAL_LOW | B < BRP | LOW |
| NORMAL_HIGH | B > BOP | HIGH |
| FAULT | Internal Fault | VPU |
| EXTERNAL_FAULT | Niepoprawne napięcie | poza zakresem |

## 11. Zalecenia

- używać wejścia cyfrowego do detekcji stanu,
- okresowo mierzyć VOUT przez ADC,
- traktować FAULT jako błąd krytyczny,
- zgłaszać niepoprawne poziomy napięcia jako usterkę okablowania.

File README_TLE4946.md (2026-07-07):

# Water Detection - TLE4946

Projekt detekcji poziomu wody oparty na czujnikach Halla TLE4946.

System wykrywania poziomu wody wykorzystujący trzy czujniki Halla TLE4946. Projekt składa się z modułu mikrokontrolera (Arduino) oraz dedykowanych płytek PCB do konwersji sygnału z czujników Halla na sygnał elektrodowy. System steruje trzema przekaźnikami (LOW, HIGH, SAFE) na podstawie odczytów analogowych z czujników. Napięcie zasilania VCC jest mierzone dynamicznie przez wewnętrzne źródło referencyjne AVR. Aktualne pomiary i stany przekaźników są prezentowane w czasie rzeczywistym na wyświetlaczu OLED (SSD1306) oraz na porcie szeregowym.

## 🔧 Komponenty

### Hardware
- **Czujniki Halla TLE4946** - 3 sztuki do detekcji poziomu wody
- **Arduino (AVR)** - mikrokontroler do przetwarzania sygnałów
- **Przekaźniki** - 3 sztuki (LOW, HIGH, SAFE)
- **Wyświetlacz OLED SSD1306** - 128×64 px, magistrala I2C (adres 0x3C)
- **PCB Czujnik Wody** - płytka główna czujnika
- **PCB Konwerter Hal-Elektrody** - konwerter sygnału

### Wymagane biblioteki (Arduino)
- **`avr/wdt.h`** - Watchdog Timer (wbudowana)
- **`Wire.h`** - komunikacja I2C (wbudowana)
- **`Adafruit_GFX`** - biblioteka graficzna
- **`Adafruit_SSD1306`** - obsługa wyświetlacza OLED

### Mapowanie pinów

| Sygnał | Pin Arduino | Kierunek |
|---|---|---|
| HALL_LOW  | A3 | Wejście analogowe |
| HALL_HIGH | A6 | Wejście analogowe |
| HALL_SAFE | A7 | Wejście analogowe |
| RELAY_LOW  | A0 | Wyjście cyfrowe |
| RELAY_HIGH | A1 | Wyjście cyfrowe |
| RELAY_SAFE | A2 | Wyjście cyfrowe |
| OLED SDA | A4 | I2C (dane) |
| OLED SCL | A5 | I2C (zegar) |

## 📊 Zasada działania

System odczytuje napięcie z trzech czujników Halla i steruje odpowiadającymi im przekaźnikami z histerezą:

| Próg | Napięcie | Działanie |
|---|---|---|
| **HIGH_THRESHOLD_V** | 1.5 V | Przekaźnik włączany (stan aktywny) |
| **LOW_THRESHOLD_V**  | 0.3 V | Przekaźnik wyłączany (stan nieaktywny) |

Hystereza zapobiega drganiom wyjść przy napięciach pomiędzy progami.

### Pomiar VCC
Napięcie zasilania jest mierzane przy starcie za pomocą wewnętrznego źródła referencyjnego AVR (bandgap 1.1 V) i używane do przeliczania wartości ADC na wolty.

### Watchdog Timer
Aktywowany Watchdog Timer (WDT) z timeout **1 sekunda** zapewnia automatyczny restart przy zawieszeniu systemu.

### Logowanie szeregowe
Co **500 ms** na port szeregowy wysyłane są zmierzone napięcia i stany wszystkich trzech kanałów.

### Wyświetlacz OLED
Wyświetlacz SSD1306 (128×64, I2C @ 0x3C) prezentuje interfejs użytkownika:
- **Ekran startowy** - komunikat inicjalizacji oraz zmierzone napięcie VCC
- **Ekran monitorowania** - odświeżany co **500 ms**, pokazuje napięcia czujników LOW/HIGH/SAFE oraz stany przekaźników (0/1)

## 📁 Struktura projektu

```
my_project/
├── Detector_TLE4946/
│   └── Detector_TLE4946.ino    # Kod Arduino
├── Detector_APS1145/
│   └── Detektor_APS1145.ino    # Alternatywny detektor
├── PCB_project/
│   ├── 3D_model/               # Modele 3D płytek
│   ├── EasyEda_Project/        # Projekty schematów i PCB
│   └── Gerber/                 # Pliki do produkcji PCB
└── Hal_Elec_Converter/         # Konwerter Hal-Elektrody
```

## 🚀 Uruchomienie

1. **Wgraj kod na Arduino:**
   - Otwórz plik `my_project/Detector_TLE4946/Detector_TLE4946.ino` w Arduino IDE
   - Wybierz odpowiednią płytkę (AVR) i port
   - Wgraj szkic

2. **Podłącz czujniki Halla:**
   - HALL LOW  → A3
   - HALL HIGH → A6
   - HALL SAFE → A7

3. **Podłącz przekaźniki:**
   - RELAY LOW  → A0
   - RELAY HIGH → A1
   - RELAY SAFE → A2

4. **Podłącz wyświetlacz OLED (I2C):**
   - SDA → A4
   - SCL → A5
   - VCC → 3.3V / 5V, GND → GND

5. **Monitor szeregowy:**
   - Otwórz monitor szeregowy (**115200 baud**)
   - Obserwuj zmierzone napięcia i stany przekaźników co 500 ms

## 📦 Pliki PCB

### Gerber (do produkcji)
- `Gerber_Czujnik-Wody_PCB_Czujnik-Wody_2026-02-04.zip`
- `Gerber_Konwerter-Hal-Elektrody_PCB_Konwerter-Hal-Elektrody_2026-02-06.zip`

### Modele 3D
- `OBJ_PCB_Konwerter-Hal-Elektrody_2026-02-06.zip`

## 🛠️ Narzędzia

- **Arduino IDE** - programowanie mikrokontrolera
- **EasyEDA** - projektowanie schematów i PCB
- **Adafruit GFX Library** - grafika na wyświetlaczu
- **Adafruit SSD1306** - sterownik wyświetlacza OLED

## 📝 Licencja

Projekt open-source. Szczegóły w pliku LICENSE.

## 👤 Autor

Projekt Water Detection

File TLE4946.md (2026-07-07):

# Zasada działania czujnika TLE4946-2K

Czujnik **TLE4946-2K** to precyzyjny zatrzask Halla (*High Precision Hall Effect Latch*), zaprojektowany do pracy w temperaturach roboczych do `150 °C`. Jest to układ scalony z czujnikiem Halla, charakteryzujący się niskimi progami przełączania i niską histerezą, co czyni go idealnym do zastosowań wymagających wykrywania pozycji wirnika w komutacji silników **BLDC**.

## 🧲 1. Zachowanie czujnika w obecności magnesu

Działanie czujnika opiera się na reakcji na magnetyczne progi przełączania:

- **Wykrywanie bieguna południowego** – biegun południowy o natężeniu pola powyżej progu operacyjnego **Bop** (*Operate Point*) **włącza wyjście** (*turns the output on*).
- **Wykrywanie bieguna północnego** – biegun północny o natężeniu pola przekraczającym próg zwolnienia **Brp** (*Release Point*) **wyłącza wyjście** (*turns it off*).
- **Histereza (BHYS)** – histereza magnetyczna zapobiega wielokrotnemu przełączaniu przy fluktuacjach pola magnetycznego.
- **Sygnał wyjściowy** – cyfrowy sygnał wyjściowy ze stopniem typu otwarty kolektor (*open collector output stage*), zdolnym do sinkowania prądu `20 mA`.

### Magnetyczne progi przełączania

| Parametr | Min | Typ | Max |
|---|-----|-----|-----|
| **Bop** (Operate Point) | `0.5 mT` | `2.0 mT` | `3.5 mT` |
| **Brp** (Release Point) | `-3.5 mT` | `-2.0 mT` | `-0.5 mT` |
| **BHYS** (Histereza) | `1.0 mT` | `4.0 mT` | `6.0 mT` |

> **Schemat czasowy (Timing diagram):** po osiągnięciu **Bop** wyjście **VQ** zmienia stan (np. z wysokiego na niski), a po osiągnięciu **Brp** wraca do poprzedniego stanu (np. z niskiego na wysoki).

## 🔒 2. Zachowanie przy braku lub słabym polu magnetycznym (funkcja zatrzasku)

Ponieważ TLE4946-2K jest **zatrzaskiem Halla** (*Hall Effect Latch*), przy braku lub słabym polu magnetycznym (natężenie pomiędzy progami Bop i Brp) **utrzymuje ostatni stan wyjściowy**.

- **Stan zatrzaśnięty** – po przełączeniu czujnik utrzymuje swój stan wyjściowy (ON lub OFF), dopóki nie zostanie przyłożone pole o wystarczającej sile i przeciwnej polaryzacji, przekraczające odpowiedni próg (Bop dla włączenia, Brp dla wyłączenia).
- **Brak pola magnetycznego (0 mT)** – gdy pole spadnie do zera lub jest zbyt słabe, aby przekroczyć próg, czujnik pozostaje w poprzednim stanie. To kluczowa cecha zatrzasków Halla – nie wymagają ciągłej obecności silnego pola do utrzymania stanu, co odróżnia je od czujników Halla typu przełącznikowego (*switch*).

**Przykłady:**

- Jeśli wyjście było **WŁĄCZONE** silnym biegunem południowym (`B > Bop`), a magnes zostanie usunięty lub pole osłabnie do 0 mT (lub do wartości pomiędzy Brp a Bop), wyjście **pozostanie WŁĄCZONE**, dopóki biegun północny nie przekroczy progu Brp.
- Jeśli wyjście było **WYŁĄCZONE** silnym biegunem północnym (`B < Brp`), a magnes zostanie usunięty lub pole osłabnie do 0 mT, wyjście **pozostanie WYŁĄCZONE**, dopóki biegun południowy nie przekroczy progu Bop.

Funkcja zatrzaskiwania jest istotna w aplikacjach wymagających pamięci ostatniego stanu magnetycznego, np. do śledzenia obrotów.

## ⚙️ 3. Budowa i zasada precyzyjnego działania

- **Precyzja i stabilność temperaturowa** – czujnik osiąga precyzyjne progi przełączania oraz wysoką stabilność temperaturową dzięki aktywnym obwodom kompensacyjnym i technikom siekania (*chopper techniques*) zaimplementowanym na chipie.
- **Eliminacja offsetu** – techniki te usuwają napięcia offsetowe generowane przez naprężenia indukowane temperaturą lub procesy formowania (*overmolding*), zapewniając wysoką dokładność.
- **Aktywna Kompensacja Błędów** (*Active Error Compensation*) – odrzuca offsety w stopniach sygnałowych i minimalizuje wpływ naprężeń mechanicznych na sondę Halla, wynikających z formowania, lutowania oraz innych naprężeń termicznych w obudowie.
- **Struktura wewnętrzna** – czujnik składa się z sondy Halla, generatora polaryzacji (*bias generator*), obwodów kompensacyjnych, oscylatora i tranzystora wyjściowego. Generator polaryzacji dostarcza prądy dla sondy Halla i obwodów aktywnych, a obwody kompensacyjne stabilizują zachowanie temperaturowe i redukują wariacje technologiczne. Połączenie techniki siekania z generatorem progów i komparatorem zapewnia bardzo dokładne magnetyczne punkty przełączania.

## 📋 4. Kluczowe cechy operacyjne

- **Szeroki zakres napięcia zasilania** – od `2.7 V` do `18 V`, umożliwiający pracę z nieregulowanego zasilania.
- **Odporność na odwrotną polaryzację baterii** – do `-18 V`.
- **Wysoka czułość i stabilność** magnetycznych punktów przełączania.
- **Wysoka odporność na naprężenia mechaniczne** dzięki aktywnej kompensacji błędów.
- **Doskonała stabilność temperaturowa.**
- **Niski jitter** – typowo `1 µs`.
- **Wysoka wydajność ESD** – `±4 kV HBM`.

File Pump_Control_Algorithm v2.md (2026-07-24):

# Algorytm sterowania pompą v2
## Założenia systemu
Czujnik bez pamięć typu APS11450 lub Reed Switch. Reaguje na obecność magnesu w postaci zbocza narastającego a następnie wchodzi w stan stabilny wysoki H. Gdy magnes opuszcza pole wykrywania czujnika, czujnik generuje zbocze opadające a następnie wchodzi w stan stabilny niski L. Czujnik nie zapamiętuje faktu przejścia magnesu.
Poziom dolny Op Lev 2 i górny Op Lev 1, dwa czujniki magnetyczne
Odpowiednio dobrany magnes w pływaku, występuje nakładanie pola magnetycznego na oba czujniki w środkowym zakresie ruchu pływaka pomiędzy czujnikami.
Dodatkowo mechaniczna blokada pływaka na poziomie Op Lev 2, wymuszająca aktywacje czujnika tego poziomu. Pływak nie może opaść niżej.
 
## Charakterystyka stref
Strefa	Położenie pływaka	            Op Lev 1	Op Lev 2	Uwagi

1   	Poniżej Op Lev 2	            L	        H	        Stan stabilny
2	    W obszarze Op Lev 2	            L	        H	        Stan stabilny
	    Przejście 2→3	                L→H	        H	        Zbocze Lev1 ↑
3	    Pomiędzy Op Lev 2 i Op Lev 1   	H	        H	        Stan stabilny
	    Przejście 3→4	                H	        H→L	        Zbocze Lev2 ↓
4	    W obszarze Op Lev 1	            H	        L	        Stan stabilny
	    Przejście 4→5	                H→L	        L	        Zbocze Lev1 ↓
5	    Powyżej Op Lev 1	            L	        L	        Stan stabilny

Wszystkie strefy z wyjątkiem 1 i 2 są wyraźnie rozróżnialne na podstawie stanu czujników.
Tabela opisuje ruch pływaka do góry.

## Dopuszczalna sekwencja zmian stanów
Op Lev 1 / Op Lev 2
Ruch pływaka w górę
L/H → H/H → H/L → L/L
Ruch pływaka w dół 
L/L → H/L → H/H → L/H

## Scenariusz 1 – normalna praca po włączeniu
1. Poziom wody podnosi na pozycje Op Lev 2
2. Pływak na pozycji Op Lev 2 zablokowany mechanicznie, system widzi stan H na czujniku Lev 2
3. Poziom wody podnosi się dalej
4. Pływak na pozycji między Op Lev 2 i Op Lev 1
5. Aktywuje się Lev 1 → system wykrywa zbocze narastające na Lev 1(`L → H`)
6. Stan czujnika Lev 2 pozostaje bez zmian na H 
7. Poziom wody podnosi się dalej
8. Pływak na pozycji Op Lev 1
9. Deaktywuje się Lev 2 → system wykrywa zbocze opadające na Lev 2 (`H → L`)
10. Stan czujnika Lev 1 pozostaje bez zmian na H
11. Załączenie pompy - ON
12. Poziom wody zaczyna opadać
13. Pływak na pozycji między Op Lev 2 i Op Lev 1
14. Aktywuje się Lev 2 → system wykrywa zbocze narastające na Lev 2 (`L → H`)
15. Stan czujnika Lev 1 pozostaje bez zmian na H
16. Poziom wody opada dalej
17. Pływak na pozycji Op Lev 2 zablokowany mechanicznie
18. Deaktywuje się Lev 1 → system wykrywa zbocze opadające na Lev 1(`H → L`)
19. Stan czujnika Lev 2 pozostaje bez zmian na H
20. Wyłączenie pompy - OFF
21. Poziom wody ponownie rośnie (kondensacja).
System pracuje cyklicznie pomiędzy `Op Lev 2` i `Op Lev 1`.

### Kluczowe zdarzenia sterujące
1. **Załączenie pompy** na zboczu opadającym z `Op Lev 2`.
2. **Wyłączenie pompy** na zboczu opadającym z `Op Lev 1`.
Na podstawie stanu czujników wyraźnie rozróżnialnych dla wszystkich stref z wyjątkiem 1 i 2 system wyznacza położenie pływaka i poziom wody.

## Scenariusz 2 – restart (intencjonalny lub losowy)

Po ponownym uruchomieniu poziom wody może znajdować się w dowolnym położeniu.
- Położenie pływaka może zostać wyznaczone na podstawie aktualnych stanów czujników, o ile sygnały są poprawne i jednoznaczne.
- System oczekuje na zdarzenie (zbocze) z czujnika `Op Lev 1` lub `Op Lev 2`.

## Zagrożenia

1. **Poziom wody znacznie powyżej `Op Lev 1`**  
Akcja: 	pompa powinna zostać załączona do momentu wystąpienia zdarzenia zatrzymującego pompowanie na poziomie Op Lev 2

2. **Uszkodzenie `Op Lev 1`**  
Skutek: 	pompa po załączeniu, może nie zostać wyłączona → ryzyko przegrzania pompy (ograniczenie czasowe działania pompy, detekcja uszkodzenia czujnika)

3. **Uszkodzenie `Op Lev 2`**  
Skutek: 	pompa może nie zostać włączona → ryzyko przepełnienia

4. **Brak zmiany stanu czujników przez zbyt długi czas podczas pracy pompy**  
Możliwe przyczyny: 	zablokowany pływak, 
uszkodzona pompa, 
brak kondensatu, 
odpadnięty magnes.

5. **Zakłócenia elektromagnetyczne (EM)**  
Chwilowe zmiany stanów czujników powinny zostać wykryte i odfiltrowane przez system. System powinien odrzucać sekwencje stanów i zboczy niezgodne z dopuszczalną sekwencją zmian stanów. 

## Obsługa zagrożeń

### Zagrożenie 1

Dzięki mechanicznej blokadzie pływaka oraz odpowiednio dobranemu magnesowi kombinacja stanów `Op Lev 1 = L` oraz `Op Lev 2 = L` może wystąpić wyłącznie dla strefy `5` (powyżej `Op Lev 1`).
System interpretuje ten stan jako przepełnienie zbiornika i:

- załącza pompę,
- prowadzi pompowanie do momentu osiągnięcia warunku wyłączenia na poziomie `Op Lev 2`.

Nie jest wymagana procedura inicjalizacji z wymuszonym pompowaniem.

### Zagrożenia 2 i 3

- Dla APS11450 możliwa jest diagnostyka czujnika i zgłoszenie błędu.
- Dla Reed Switch brak diagnostyki własnej, dlatego wykrywanie uszkodzeń opiera się na analizie sekwencji stanów i czasie przejść pomiędzy strefami.

### Zagrożenie 4

Chwilowe zmiany stanów czujników powinny być filtrowane.
System powinien:

- odrzucać krótkotrwałe zakłócenia,
- odrzucać sekwencje stanów i zboczy niezgodne z dopuszczalną kolejnością zmian stanów,
- zgłaszać błąd w przypadku trwałego naruszenia logiki działania.

Do analizy wykorzystywane są:

- aktualne stany czujników,
- zbocza narastające,
- zbocza opadające.

## Koncepcja algorytmu (FSM)

Algorytm sterowania można zaimplementować jako automat skończony (FSM), którego zadaniem jest:

- wyznaczanie aktualnej strefy położenia pływaka na podstawie stanów czujników,
- weryfikacja poprawności przejść pomiędzy strefami na podstawie wykrywanych zboczy,
- sterowanie pompą poprzez wykonywanie akcji przypisanych do określonych przejść automatu.

Stany stabilne automatu odpowiadają kolejnym strefom położenia pływaka, natomiast zbocza stanowią zdarzenia powodujące przejścia pomiędzy tymi stanami.

Akcje sterujące:

- załączenie pompy – zbocze opadające `Op Lev 2`,
- wyłączenie pompy – zbocze opadające `Op Lev 1`.

Dzięki takiej architekturze bieżące położenie pływaka określane jest na podstawie aktualnych stanów czujników, natomiast poprawność działania układu nadzorowana jest przez automat FSM, który akceptuje wyłącznie dopuszczalne sekwencje zmian stanów.

## Przykładowe stany FSM

- `LEVEL_OPLEV2`
- `BETWEEN_LEVELS`
- `LEVEL_OPLEV1`
- `ABOVE_OPLEV1`
- `FAULT`

## Diagnostyka

System powinien wykrywać nieprawidłowości zarówno na podstawie czasu przejść pomiędzy strefami, jak i poprawności sekwencji stanów.
Do wykrywanych usterek należą:

- zablokowany pływak,
- brak kondensatu podczas pracy pompy,
- uszkodzona pompa,
- odpadnięty magnes,
- uszkodzony czujnik,
- sekwencja stanów niezgodna z dopuszczalnym modelem ruchu pływaka.

W przypadku wykrycia niedozwolonej sekwencji stanów lub przekroczenia dopuszczalnego czasu przejścia pomiędzy strefami sterownik powinien przejść do stanu `FAULT` i zgłosić błąd.

## Przy nowych założeniach, w stosunku do v1, zostały usunięte

- sekcja „Sekwencja startowa (INIT)”,
- procedura wymuszonego pompowania,
- sekcja „Ograniczenie informacyjne układu”.

W poprzedniej wersji były one konieczne, ponieważ dwa czujniki bez pamięci nie pozwalały odtworzyć położenia pływaka po restarcie.
W obecnej architekturze, dzięki blokadzie mechanicznej oraz nakładaniu pól magnetycznych, wszystkie istotne stany (w tym `L/L` jako strefa `5`) są jednoznacznie interpretowalne, więc problem ten został wyeliminowany.

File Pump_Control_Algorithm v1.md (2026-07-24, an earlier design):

# Algorytm sterowania pompą

## Założenia systemu

Czujnik bez pamięci typu **APS11450** lub **Reed Switch** reaguje na obecność magnesu:

- pojawia się zbocze narastające, a następnie stan stabilny wysoki (`H`),
- po opuszczeniu pola detekcji pojawia się zbocze opadające, a następnie stan stabilny niski (`L`).

Czujnik nie zapamiętuje faktu przejścia magnesu.

W układzie są dwa poziomy i dwa czujniki magnetyczne:

- **Op Lev 2** – poziom dolny,
- **Op Lev 1** – poziom górny.

Magnes w pływaku jest krótki, więc nie podtrzymuje stanu czujnika `Op Lev 2` podczas przejścia w kierunku `Op Lev 1`.

---

## Scenariusz 1 – normalna praca po włączeniu

1. Poziom wody w grupie dolnej (`Bottom`) podnosi się.
2. Aktywuje się `Op Lev 2` → system wykrywa zbocze narastające (`L → H`).
3. Pompa zostaje wyłączona (jeśli była wcześniej załączona).
4. Poziom wody rośnie dalej.
5. Deaktywuje się `Op Lev 2` → system wykrywa zbocze opadające (`H → L`).
6. Poziom wody rośnie dalej.
7. Aktywuje się `Op Lev 1` → system wykrywa zbocze narastające (`L → H`).
8. Pompa zostaje załączona.
9. Poziom wody zaczyna opadać.
10. Deaktywuje się `Op Lev 1` → system wykrywa zbocze opadające (`H → L`).
11. Poziom wody opada dalej.
12. Aktywuje się `Op Lev 2` → system wykrywa zbocze narastające (`L → H`).
13. Pompa zostaje wyłączona.
14. Poziom wody ponownie rośnie (kondensacja).

System pracuje cyklicznie pomiędzy `Op Lev 2` i `Op Lev 1`.

### Kluczowe zdarzenia sterujące

1. **Załączenie pompy** na zboczu narastającym z `Op Lev 1`.
2. **Wyłączenie pompy** na zboczu narastającym z `Op Lev 2`.

Na podstawie obserwacji zboczy i ich sekwencji system estymuje położenie pływaka i poziom wody.

---

## Scenariusz 2 – restart (intencjonalny lub losowy)

Po ponownym uruchomieniu poziom wody może znajdować się w dowolnym położeniu.

- System oczekuje na zdarzenie (zbocze) z czujnika `Op Lev 1` lub `Op Lev 2`.
- W momencie startu położenie pływaka i poziomu wody jest nieznane.
- Każde poprawne przejście pływaka przez czujnik (ze zboczem) aktualizuje estymowany stan układu.

---

## Zagrożenia

1. **Poziom wody znacznie powyżej `Op Lev 1`**  
   Magnes nie aktywuje żadnego czujnika, więc nie pojawi się zbocze narastające.  
   Skutek: pompa może nie zostać załączona → ryzyko przepełnienia grupy dolnej.

2. **Uszkodzenie `Op Lev 1`**  
   Skutek: pompa może nie zostać załączona → ryzyko przepełnienia grupy dolnej.

3. **Uszkodzenie `Op Lev 2`**  
   Skutek: pompa może nie zostać wyłączona → ryzyko przegrzania pompy.

4. **Zakłócenia elektromagnetyczne (EM)**  
   Chwilowe zmiany stanów czujników powinny zostać wykryte i odfiltrowane.

### Obsługa zagrożeń

#### Zagrożenie 1

Tego przypadku nie da się bezpośrednio zdiagnozować bez procedury inicjalizacyjnej. Dlatego należy zastosować **wymuszone pompowanie po starcie** aż do wykrycia aktywacji dowolnego czujnika.

Wymuszone pompowanie musi mieć ograniczenie czasowe.

Jeśli w zadanym oknie czasowym nie wystąpi aktywacja żadnego czujnika, system:

- zatrzymuje pompowanie,
- przyjmuje roboczo, że pływak jest poniżej `Op Lev 2`.

#### Zagrożenia 2 i 3

- Dla `APS11450` mogą być rozpoznane diagnostycznie i zgłoszone jako błąd.
- Dla `Reed Switch` brak diagnostyki własnej czujnika, więc zagrożenia pozostają.

#### Zagrożenie 4

Chwilowe zmiany stanów czujników powinny być filtrowane. Jeśli system zna aktualne położenie pływaka/wody, powinien:

- odrzucać stany niestabilne,
- odrzucać zdarzenia niezgodne z bieżącym stanem automatu `FSM`.

Do estymacji dostępne są:

- zbocza narastające,
- zbocza opadające,
- chwilowe stany stabilne wejść.

---

## Charakterystyka stref

| Strefa | Położenie pływaka | Op Lev 1 | Op Lev 2 | Uwagi |
|:---:|---|:---:|:---:|---|
| 1 | Poniżej `Op Lev 2` | L | L | Stan stabilny |
| 2 | W obszarze `Op Lev 2` | L | H | Stan przejściowy – generowane zbocza |
| 3 | Pomiędzy `Op Lev 2` i `Op Lev 1` | L | L | Stan stabilny |
| 4 | W obszarze `Op Lev 1` | H | L | Stan przejściowy – generowane zbocza |
| 5 | Powyżej `Op Lev 1` | L | L | Stan stabilny |

---

## Koncepcja algorytmu (`FSM`)

Algorytm sterowania można zaimplementować jako automat skończony (`FSM`), który:

- estymuje położenie pływaka na podstawie sekwencji zboczy z `Op Lev 1` i `Op Lev 2`,
- steruje pompą na podstawie przejść pomiędzy stanami.

Uwzględniane są dwa kierunki ruchu:

- wzrost poziomu,
- spadek poziomu.

Przejścia między stanami są wyzwalane wyłącznie przez poprawnie zweryfikowane zdarzenia.

Akcje sterujące:

- załączenie pompy: przejście przez `Op Lev 1` (zbocze narastające),
- wyłączenie pompy: przejście przez `Op Lev 2` (zbocze narastające).

Dzięki temu decyzje nie wynikają z chwilowego stanu wejść, tylko z logiki sekwencji zdarzeń i aktualnego stanu `FSM`.

### Przykładowe stany `FSM`

- `INIT`
- `BELOW_OPLEV2`
- `PASSING_OPLEV2`
- `BETWEEN_LEVELS`
- `PASSING_OPLEV1`
- `ABOVE_OPLEV1`
- `FAULT`

---

## Sekwencja startowa (`INIT`)

1. Po uruchomieniu sterownik przechodzi do stanu `INIT`.
2. Poziom wody jest nieznany, więc system nie przechodzi od razu do normalnej pracy.
3. Uruchamiana jest procedura rozpoznania położenia pływaka.

### Etap 1 – wymuszone pompowanie

- Załącz pompę.
- Uruchom licznik czasu (np. 10–30 s, zależnie od instalacji).
- Oczekuj na pierwsze poprawne zbocze narastające:
  - `Op Lev 1 ↑` → pływak osiągnął górny poziom, przejdź do właściwego stanu `FSM` i kontynuuj pracę.
  - `Op Lev 2 ↑` → pływak osiągnął dolny poziom, przejdź do właściwego stanu `FSM` i kontynuuj pracę.

### Etap 2 – timeout

Jeżeli w zadanym czasie nie wystąpi żadne zbocze:

- wyłącz pompę,
- przyjmij roboczo, że pływak jest poniżej `Op Lev 2`,
- przejdź do stanu odpowiadającego tej strefie,
- rozpocznij normalną pracę.

---

## Dodatkowa diagnostyka

Jeżeli podczas inicjalizacji pojawi się sekwencja niemożliwa (np. jednoczesna aktywacja obu czujników, jeśli konstrukcja tego nie dopuszcza, albo seria sprzecznych zboczy), sterownik powinien:

- odrzucić zdarzenie jako zakłócenie, lub
- przejść do stanu `FAULT` i zgłosić błąd.

Brak oczekiwanego zbocza w dopuszczalnym czasie podczas normalnej pracy należy interpretować jako awarię układu (pompa, czujnik, pływak lub instalacja).

Możliwe wykrywane usterki:

- zablokowany pływak,
- brak kondensatu,
- uszkodzona pompa,
- odpadnięty magnes,
- uszkodzony czujnik.

---

## Ograniczenie informacyjne układu

Jeżeli po restarcie pływak znajduje się już powyżej `Op Lev 1`, a pompa nie jest w stanie obniżyć poziomu wody, nie pojawi się żadne zbocze, bo magnes nie przejdzie przez obszar żadnego czujnika.

W takiej sytuacji procedura z timeoutem może błędnie uznać, że pływak jest poniżej `Op Lev 2`.

Tego przypadku **nie da się jednoznacznie rozpoznać**, używając wyłącznie dwóch czujników bez pamięci. To ograniczenie informacyjne układu, a nie wada algorytmu.

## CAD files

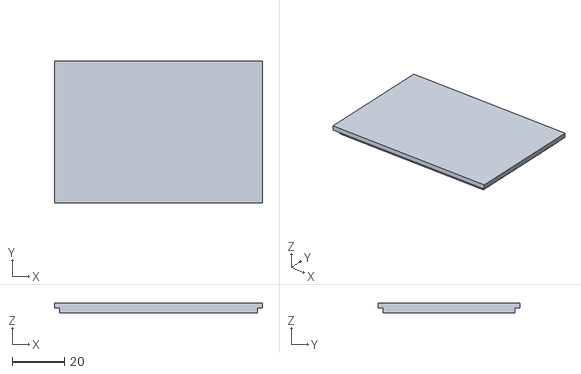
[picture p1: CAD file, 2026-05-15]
doc/Housing/Pokrywa.stl
79.4 x 54.3 x 4.00

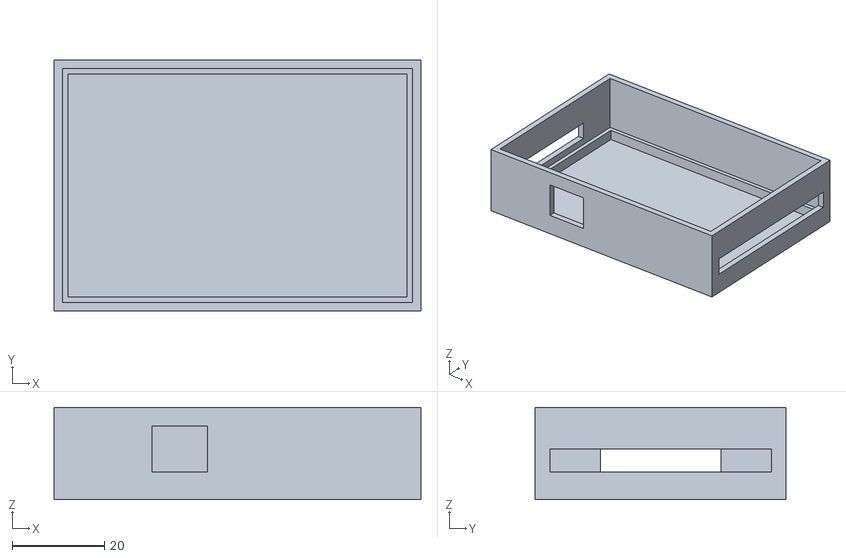
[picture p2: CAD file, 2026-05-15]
doc/Housing/Pudlo.stl
79.4 x 54.3 x 20.0

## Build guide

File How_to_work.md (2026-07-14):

# How to work — metoda pracy odporna na rozłączenia LLM

> Plik roboczy dla asystenta (GitHub Copilot). Powstał, bo sesja LLM
> **często się rozłącza** (np. `net::ERR_CONNECTION_CLOSED`) i praca
> zaczyna się od nowa. Ten plik jest **jednym punktem wznowienia** —
> zawiera metodę pracy **oraz** aktualny stan zadania.

---

## 0. Zasada nadrzędna: PERSISTENCE-FIRST

Kontekst w pamięci LLM **znika** po rozłączeniu. Pliki na dysku **zostają**.

**Wniosek:** po każdym najmniejszym kroku natychmiast zapisuj wynik na
dysk (plik kodu + wpis w sekcji [Log postępu](#log-postępu)). Nigdy nie
trzymaj gotowej pracy tylko „w głowie” / w odpowiedzi czatu.

---

## 1. Reguły pracy

1. **Małe, atomowe kroki** — jeden krok = jedna funkcja / jeden moduł /
   jedna sekcja pliku. Krok ma dać się ukończyć w kilka minut.
2. **Zapis po każdym kroku** — użyj narzędzia do tworzenia/edycji pliku,
   a potem dopisz wpis do [Log postępu](#log-postępu) z datą i statusem.
3. **Walidacja przyrostowa** — po każdym module sprawdź błędy
   (get_errors). Nie kumuluj niesprawdzonego kodu.
4. **Jeden wskaźnik `>>> RESUME HERE <<<`** — zawsze wskazuje następny
   krok. Świeża sesja czyta ten plik, skacze do wskaźnika i kontynuuje.
5. **Idempotentność** — przed utworzeniem pliku sprawdź, czy już
   istnieje (file_search), aby nie nadpisać postępu.
6. **Nie ufaj todo-liście po restarcie** — narzędziowa lista TODO może
   nie przetrwać nowej sesji. **Źródłem prawdy jest TEN plik na dysku.**
7. **Commit warto robić często** — po ukończeniu modułu można wykonać
   commit (użytkownik używa git), co daje dodatkową kopię stanu.

---

## 2. Pętla robocza (powtarzaj)

```text
1. Otwórz How_to_work.md → znajdź „>>> RESUME HERE <<<”.
2. Wykonaj JEDEN krok (mały).
3. Zapisz plik wynikowy na dysk.
4. get_errors na zmienionym pliku.
5. Dopisz wpis do „Log postępu” (data, co zrobiono, wynik).
6. Przesuń „>>> RESUME HERE <<<” na kolejny krok.
7. (opcjonalnie) commit.
8. Wróć do 1.
```

---

## 3. Procedura wznowienia po rozłączeniu

1. Przeczytaj ten plik w całości (jest krótki i samowystarczalny).
2. Sekcja [Snapshot projektu](#4-snapshot-projektu-stan-utrwalony) ma
   wszystkie decyzje (piny, progi, tabele, kody błędów) — nie trzeba
   ponownie czytać całej specyfikacji.
3. Znajdź `>>> RESUME HERE <<<` w [Rozbiciu zadania](#5-rozbicie-zadania).
4. Sprawdź na dysku, co realnie istnieje (file_search / read_file), bo
   ostatni krok mógł się zapisać tuż przed rozłączeniem.
5. Kontynuuj pętlę roboczą z sekcji 2.

---

## 4. Snapshot projektu (stan utrwalony)

**Zadanie:** przygotować szkic `Detektor_APS11450.ino` zgodnie z
`Soft_Req_Spec_APS11450.md` oraz `APS11450.md`.

**Cel docelowego pliku:**
`my_project/Detector_APS11450/Detektor_APS11450.ino`

**Źródła specyfikacji:**
- `Soft_Req_Spec_APS11450.md` — architektura, poziomy, automat stanów,
  tabela przejść, kombinacje niedozwolone.
- `APS11450.md` — pasma napięć, stany wyjścia, diagnostyka.
- Wzorzec sprzętowy do ponownego użycia: `Detektor_APS1145.ino`.

### 4.1. Konfiguracja sprzętu

| Element | Wartość |
| --- | --- |
| HALL_LOW_PIN | A3 (wejście analogowe, diagnostyka ADC) |
| HALL_HIGH_PIN | A6 |
| HALL_SAFE_PIN | A7 |
| RELAY_LOW_PIN | A0 (wyjście) |
| RELAY_HIGH_PIN | A1 |
| RELAY_SAFE_PIN | A2 |
| OLED | SSD1306 128×64, I2C, adres 0x3C |
| Serial | 115200 |
| WDT | 1 s (WDTO_1S) |

Funkcje do ponownego użycia z `Detektor_APS1145.ino`:
- `readVcc()` — bandgap, `result = 1125300L / ADC`.
- `readADCStable(pin)` — podwójny odczyt z `delayMicroseconds(20)`.
- `adcToVoltage(adc) = (adc / 1023.0) * Vcc`.

### 4.2. Klasyfikacja napięcia APS11450 (pasma jako % VPU = Vcc)

| Zakres | Klasa |
| --- | --- |
| 0–10% | SIG_EXT_FAULT (usterka zewnętrzna) |
| 10–30% | SIG_LOW (poprawny LOW) |
| 30–70% | SIG_EXT_FAULT (usterka zewnętrzna) |
| 70–90% | SIG_HIGH (poprawny HIGH) |
| 90–100% | SIG_INT_FAULT (Internal Fault, VOUT=VPU) |

Progi jako ułamki Vcc: `0.10, 0.30, 0.70, 0.90`.
Enum: `enum SignalClass { SIG_LOW, SIG_HIGH, SIG_EXT_FAULT, SIG_INT_FAULT };`

### 4.3. Model poziomu i przejść

Surowe bity `raw = (low, high, safe)`:

| raw | Poziom |
| --- | --- |
| 000 | EMPTY |
| 100 | LEVEL1 |
| 110 | LEVEL2 |
| 111 | LEVEL3 |

Kombinacje **niedozwolone** (trzymaj poprzedni poziom): `010, 001, 101, 011`.

Wirtualne elektrody wg poziomu (sekcja 4 spec): EMPTY=000, L1=100,
L2=110, L3=111. Relay Manager: `R1=E1, R2=E2, R3=E3`.

Enum poziomów: `UNKNOWN, EMPTY, LEVEL1, LEVEL2, LEVEL3, FAULT`.

Reguły przejść:
- tylko zmiany o **sąsiedni** poziom,
- zatwierdzenie po czasie stabilizacji `STABLE_MS ≈ 1000 ms`,
- dowolna usterka sensora → `FAULT` + Alarm; `FAULT → UNKNOWN` (odzysk),
- polityka FAULT (sekcja 3 spec, konfigurowalna): `FAULT_RELAYS` = wszystkie ON (stan alarmowy — urządzenie zewnętrzne musi zareagować błędem).

### 4.4. Kody diagnostyczne

| Kod | Znaczenie |
| --- | --- |
| E00 | brak błędu |
| E10 / E11 / E12 | Internal Fault: low / high / safe |
| E20 / E21 / E22 | External Fault: low / high / safe |
| E30 | kombinacja niedozwolona (niespójne stany) |
| E31 | przeskok poziomu |
| E32 | zbyt długi stan przejściowy (timeout) |
| E33 | błąd sekwencji |
| E34 | utrata synchronizacji |

### 4.5. Stałe czasowe (propozycja)

`STABLE_MS=1000`, `INIT_SAMPLE_MS=1500`, `TRANSIENT_TIMEOUT_MS=5000`,
`logInterval=500`.

---

## 5. Rozbicie zadania

Legenda: `[ ]` do zrobienia · `[~]` w toku · `[x]` gotowe.

- [x] K0. Utrwalić metodę i stan → **ten plik** (`How_to_work.md`).
- [x] K1. Utworzyć plik `.ino` + nagłówek + `#include` + `#define` pinów
  + stałe (progi ułamkowe, czasy, `FAULT_RELAYS`).
- [x] K2. Enum `SignalClass` + `classifySignal(float vFrac)`.
- [x] K3. Struktura `SensorState{low,high,safety,lowFault,highFault,safetyFault}`.
- [x] K4. Helpery HW: `readVcc`, `readADCStable`, `adcToVoltage`.
- [x] K5. Sensor Manager: `readSensors()` → wypełnia `SensorState`
  (fault = internal||external, active = SIG_HIGH). Bez interpretacji poziomu.
- [x] K6. Enum poziomów + `levelFromRaw()` + `isValidRaw()` + `rawFromSensors()`.
- [ ] K7. Level Resolver: `resolveLevel(SensorState)` — fault→FAULT(kod);
  raw niedozwolony→trzymaj+E30 (E32 gdy za długo); poprawny & sąsiedni &
  stabilny→commit (E31 gdy przeskok). Zwraca poziom + kod diagnostyczny.
- [x] K8. Elektrody: `electrodesFromLevel(level, &E1,&E2,&E3)`.
- [x] K9. Relay Manager: `applyElectrodes(E1,E2,E3)`; w FAULT polityka `FAULT_RELAYS`.
- [x] K10. `setup()`: WDT off, Serial, piny przekaźników OUTPUT (trzymaj
  poprzedni=OFF), OLED, pomiar Vcc; restart wg sekcji 6 — próbkowanie
  `INIT_SAMPLE_MS`, głosowanie większościowe → najbardziej prawdopodobny
  poziom; init elektrod+przekaźników; log `INIT_COMPLETE`; WDT on 1 s.
- [x] K11. `loop()`: `wdt_reset`; `readSensors`; `resolveLevel`;
  `applyElectrodes`; co 500 ms log Serial (napięcia, sygnały, poziom,
  elektrody, kod) + OLED (poziom, E1-3, kod).
- [x] K12. Walidacja: `get_errors` na `.ino`; zgodność z tabelą przejść
  (sekcja 9) i kombinacjami niedozwolonymi (sekcja 10).
  **`>>> UKOŃCZONO — wszystkie kroki K0..K12 gotowe. Opcjonalnie: kompilacja w Arduino IDE (AVR toolchain). <<<`**

---

## Log postępu

> Format: `RRRR-MM-DD — [Kx] opis — wynik`. Dopisuj na końcu po każdym kroku.

- 2026-07-07 — [K0] Utworzono `How_to_work.md` z metodą pracy i pełnym
  snapshotem stanu (piny, pasma napięć, poziomy, tabela przejść, kody
  błędów). Następny krok: K1 (nagłówek + config `.ino`). — OK
- 2026-07-07 — [K1] Utworzono `my_project/Detector_APS11450/Detektor_APS11450.ino`:
  nagłówek + `#include` (wdt, Wire, Adafruit GFX/SSD1306), OLED 0x3C,
  piny Hall A3/A6/A7, przekaźniki A0/A1/A2 (E1-E3), `ADC_MAX`, `SERIAL_BAUD`,
  globalne `Vcc`, progi ułamkowe VPU (0.10/0.30/0.70/0.90), czasy
  (`STABLE_MS`/`INIT_SAMPLE_MS`/`TRANSIENT_TIMEOUT_MS`/`logInterval`),
  polityka `FAULT_RELAY_*` = ON (stan alarmowy). `get_errors` → brak błędów. Następny: K2. — OK
- 2026-07-07 — [K2] Dodano `enum SignalClass {SIG_LOW,SIG_HIGH,SIG_EXT_FAULT,
  SIG_INT_FAULT}` + `classifySignal(float vFrac)` wg pasm APS11450.md sek. 6
  (progi 0.10/0.30/0.70/0.90 VPU). — OK
- 2026-07-07 — [K3] Dodano `struct SensorState{low,high,safety,lowFault,
  highFault,safetyFault}` (aktywnosc = SIG_HIGH, fault = internal||external). — OK
- 2026-07-07 — [K4] Dodano helpery HW `readVcc()` (bandgap, mV),
  `readADCStable(pin)`, `adcToVoltage(adc)` (wzorzec z APS1145).
  `get_errors` → brak błędów. Następny: K5. — OK
- 2026-07-07 — [K5] Dodano Sensor Manager: `readSensorClass(pin)` +
  `readSensors()` (vFrac = ADC/1023, active = SIG_HIGH, fault =
  INT||EXT). `SensorState` rozszerzono o `lowClass/highClass/safetyClass`
  (rozroznienie internal/external dla kodow E1x/E2x; kontrakt 6 bool ze spec
  zachowany). — OK
- 2026-07-07 — [K6] Dodano `enum Level {UNKNOWN,EMPTY,LEVEL1,LEVEL2,LEVEL3,
  FAULT}`, `enum DiagCode {E00..E34}`, `rawFromSensors()` (low<<2|high<<1|
  safety), `isValidRaw()` (000/100/110/111), `levelFromRaw()`.
  UWAGA: `get_errors` zglasza tylko brak sciezki `avr/wdt.h` (toolchain
  Arduino nieskonfigurowany w VS Code) — nie jest to blad logiki/skladni;
  ten sam objaw dotyczy wzorca APS1145. Następny: K7. — OK
- 2026-07-07 — [K7] Dodano Level Resolver: `struct LevelResult{level,code}`,
  stan `currentLevel/candidateLevel/candidateSince/transientSince`,
  `levelIndex()`, `faultCode()` (E10-E22, internal przed external),
  `resolverInit()`, `resolveLevel()` (FAULT->kod; FAULT->UNKNOWN odzysk;
  raw niedozwolony->trzymaj E30/E32; stabilizacja STABLE_MS; commit sasiedni
  E00 / przeskok E31; UNKNOWN->przyjmij poprawny jak INIT). — OK
- 2026-07-07 — [K8] Dodano `electrodesFromLevel(level,&e1,&e2,&e3)`
  (EMPTY=000,L1=100,L2=110,L3=111; UNKNOWN/FAULT->000). — OK
- 2026-07-07 — [K9] Dodano Relay Manager: `applyElectrodes(e1,e2,e3)`
  (R1=E1,R2=E2,R3=E3) oraz `applyLevel(lvl)` (FAULT->FAULT_RELAYS ON;
  UNKNOWN->trzymaj poprzedni; inne->elektrody). `get_errors` → tylko nota
  includePath AVR. Następny: K10. — OK
- 2026-07-07 — [K10] Dodano `setup()`: wdt_disable, Serial, piny przekaźników
  OUTPUT+OFF (bezpieczny start), OLED splash, `Vcc=readVcc()/1000`, restart
  wg sekcji 6 (próbkowanie `INIT_SAMPLE_MS`, głosowanie `votes[4]`, pomijanie
  fault/niedozwolonych), `resolverInit`+`applyLevel`, log `INIT_COMPLETE`,
  `wdt_enable(WDTO_1S)`. Helpery: `sigChar`, `levelName`, `diagCodeStr`,
  `indexToLevel`, `lastLogTime`. — OK
- 2026-07-07 — [K11] Dodano `loop()`: `wdt_reset`; `readSensors`;
  `resolveLevel`; `applyLevel`; co `logInterval`=500 ms log Serial
  (V L/H/S, sygnały L/H/X/I, raw bity, poziom, E1-3, kod Exx) + OLED. — OK
- 2026-07-07 — [K12] Przegląd całego `.ino`: zgodność z tabelą przejść
  (sekcja 9: EMPTY<->L1<->L2<->L3, dowolny->FAULT) i kombinacjami
  niedozwolonymi (sekcja 10: 010/001/101/011 -> trzymaj+E30/E32).
  `get_errors` → wyłącznie brak sciezki `avr/wdt.h` (toolchain Arduino,
  squiggles wyłączone) — bez błędów logiki/składni. PROJEKT UKOŃCZONY. — OK
- 2026-07-07 — [HOTFIX] Naprawiono błąd kompilacji Arduino IDE
  (`does not name a type`) wynikający z auto-generowanych prototypów:
  przeniesiono wszystkie definicje typów (`SignalClass`, `SensorState`,
  `Level`, `DiagCode`, `LevelResult`) do jednego bloku nad pierwszą funkcją,
  usunięto duplikaty niżej w pliku. `get_errors` w VS Code: tylko
  środowiskowe `avr/wdt.h` (includePath/toolchain). — OK

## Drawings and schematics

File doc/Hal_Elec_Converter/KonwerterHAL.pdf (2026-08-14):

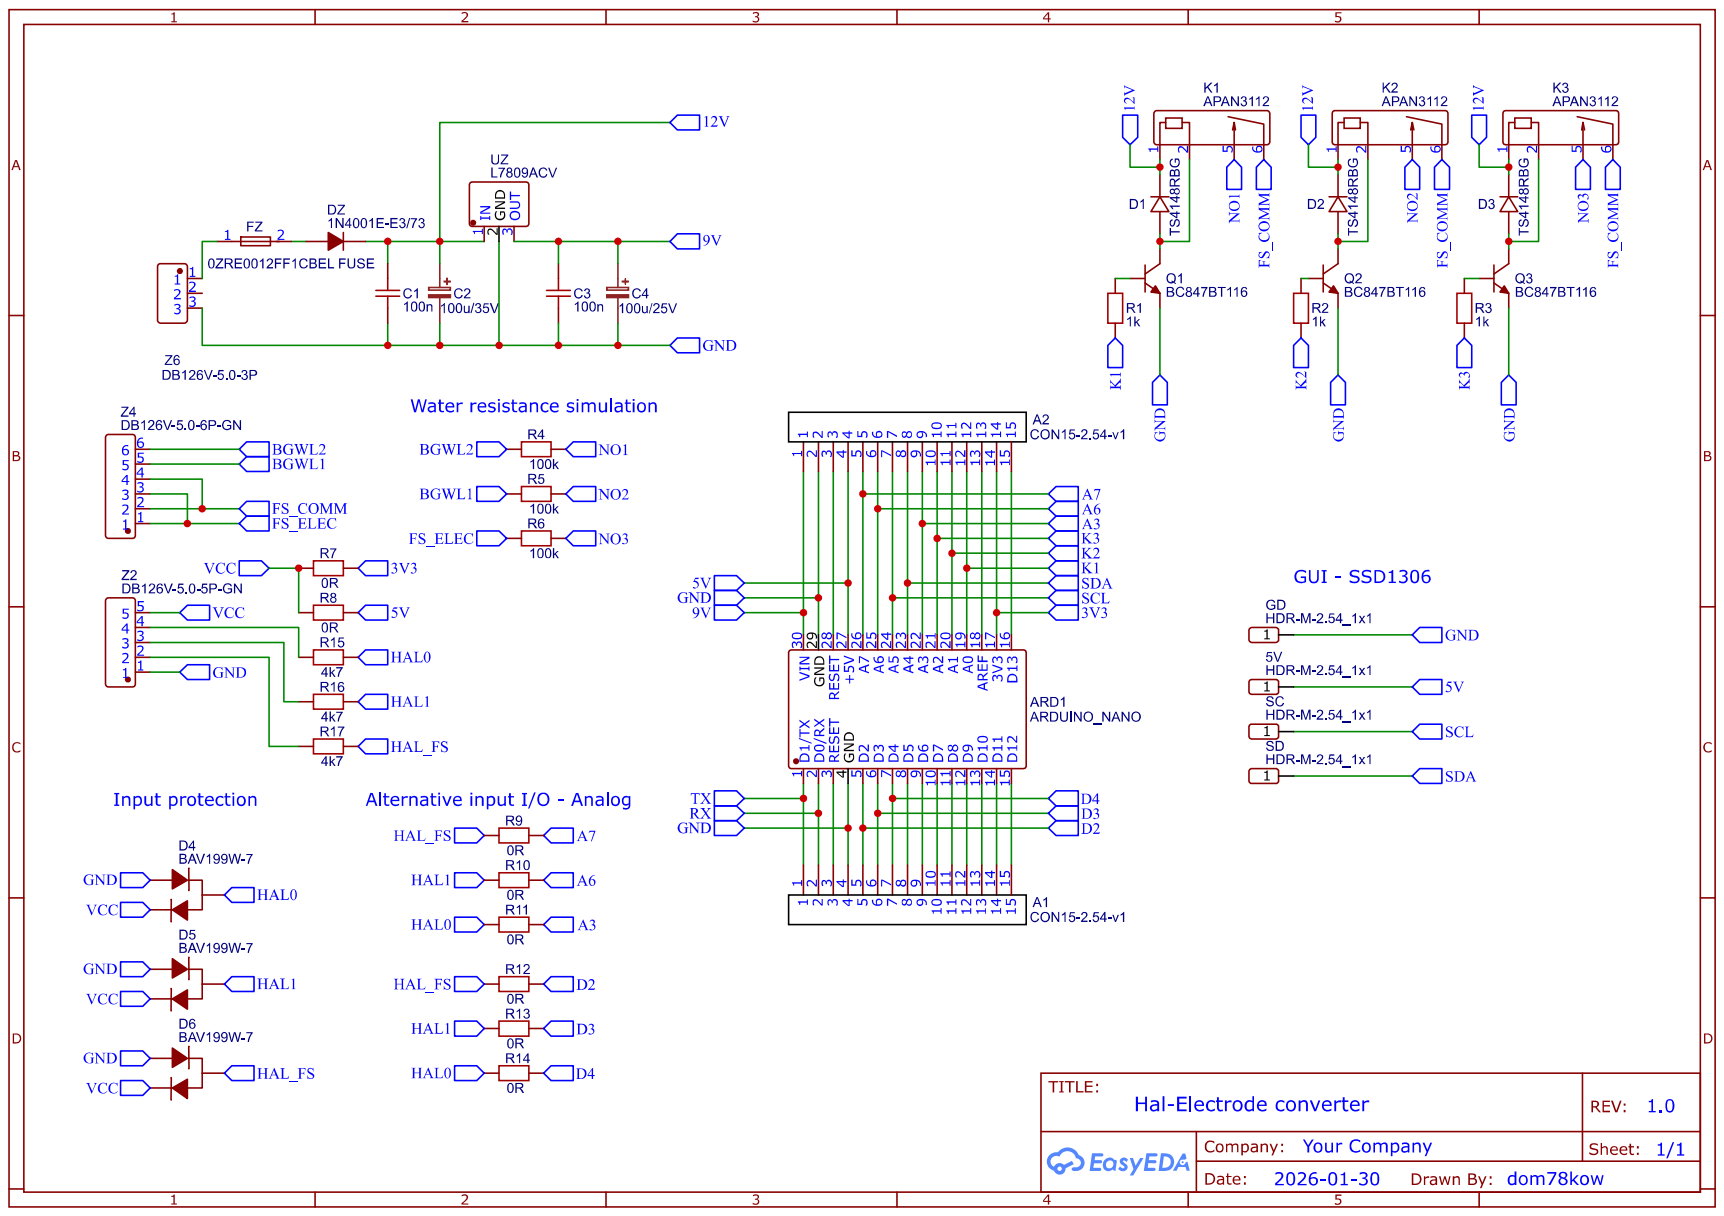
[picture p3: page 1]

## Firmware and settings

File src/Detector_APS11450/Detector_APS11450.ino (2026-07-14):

/*
 * ============================================================================
 *  Detektor poziomu wody - APS11450
 * ============================================================================
 *
 *  Sterownik poziomu wody oparty o trzy czujniki Halla APS11450 oraz plywak
 *  z magnesem. Dla sterownika zewnetrznego uklad zachowuje sie identycznie
 *  jak trzy elektrody zanurzeniowe (E1-E3).
 *
 *  Architektura (Soft_Req_Spec_APS11450.md, sekcja 2):
 *      APS11450 x3 -> Sensor Manager -> Level Resolver -> Relay Manager
 *
 *      - Sensor Manager : tylko sprzet (odczyt LOW/HIGH/SAFETY, ADC,
 *                         Internal/External Fault). Nie interpretuje poziomu.
 *      - Level Resolver : jedyny modul z pamiecia stanu. Filtruje stany
 *                         przejsciowe, wykrywa przeskoki, diagnostyka logiczna.
 *      - Relay Manager  : mapuje poziom (E1-E3) na przekazniki.
 *
 *  Zrodla:
 *      - Soft_Req_Spec_APS11450.md (architektura, poziomy, automat, tabela
 *        przejsc sekcja 9, niedozwolone kombinacje sekcja 10)
 *      - APS11450.md (pasma napiec sekcja 6, diagnostyka sekcja 7)
 *      - Detektor_APS1145.ino (wzorzec sprzetowy: readVcc/readADCStable/OLED)
 *
 *  UWAGA: plik budowany przyrostowo wg How_to_work.md (kroki K1..K12).
 *         Aktualny krok wskazuje marker ">>> RESUME HERE <<<" w How_to_work.md.
 * ============================================================================
 */

#include <avr/wdt.h>
#include <Wire.h>
#include <Adafruit_GFX.h>
#include <Adafruit_SSD1306.h>

// ---------------------------------------------------------------------------
// Wyswietlacz OLED SSD1306 128x64, I2C, adres 0x3C
// ---------------------------------------------------------------------------
#define SCREEN_WIDTH        128
#define SCREEN_HEIGHT       64
#define OLED_RESET          -1
#define SCREEN_ADDRESS      0x3C

Adafruit_SSD1306 display(SCREEN_WIDTH, SCREEN_HEIGHT, &Wire, OLED_RESET);

// ---------------------------------------------------------------------------
// Piny czujnikow Halla APS11450 (wejscia analogowe, diagnostyka przez ADC)
// ---------------------------------------------------------------------------
#define HALL_LOW_PIN        A3
#define HALL_HIGH_PIN       A6
#define HALL_SAFE_PIN       A7

// ---------------------------------------------------------------------------
// Piny przekaznikow (wyjscia) - odpowiadaja wirtualnym elektrodom E1-E3
// ---------------------------------------------------------------------------
#define RELAY_LOW_PIN       A0      // E1 / R1
#define RELAY_HIGH_PIN      A1      // E2 / R2
#define RELAY_SAFE_PIN      A2      // E3 / R3

// ---------------------------------------------------------------------------
// Parametry ADC / zasilania
// ---------------------------------------------------------------------------
#define ADC_MAX             1023.0
#define SERIAL_BAUD         115200

float Vcc = 0.0;                    // zmierzone napiecie zasilania [V] (VPU)

// ---------------------------------------------------------------------------
// Klasyfikacja napiecia APS11450 - pasma jako ulamek VPU (=Vcc)
// (APS11450.md sekcja 6)
//
//   0 - 10%  -> External Fault (usterka zewnetrzna)
//  10 - 30%  -> poprawny LOW
//  30 - 70%  -> External Fault (usterka zewnetrzna)
//  70 - 90%  -> poprawny HIGH
//  90 -100%  -> Internal Fault (VOUT = VPU)
// ---------------------------------------------------------------------------
const float VFRAC_EXTLOW_MAX = 0.10f;   // granica 0-10%
const float VFRAC_LOW_MAX    = 0.30f;   // granica LOW  10-30%
const float VFRAC_EXTMID_MAX = 0.70f;   // granica usterki 30-70%
const float VFRAC_HIGH_MAX   = 0.90f;   // granica HIGH 70-90%
                                        // powyzej 0.90 -> Internal Fault

// ---------------------------------------------------------------------------
// Stale czasowe (How_to_work.md sekcja 4.5)
// ---------------------------------------------------------------------------
const unsigned long STABLE_MS            = 1000;   // czas stabilizacji poziomu
const unsigned long INIT_SAMPLE_MS       = 1500;   // okno probkowania po restarcie
const unsigned long TRANSIENT_TIMEOUT_MS = 5000;   // maks. czas stanu przejsciowego
const unsigned long logInterval          = 500;    // okres logowania Serial/OLED

// ---------------------------------------------------------------------------
// Polityka bezpieczenstwa w stanie FAULT (Soft_Req_Spec sekcja 3)
// FAULT_RELAYS = wszystkie przekazniki ON (stan alarmowy - urzadzenie zewnetrzne
// musi zareagowac na ten stan i wyrzucic blad)
// ---------------------------------------------------------------------------
#define FAULT_RELAY_LOW     HIGH
#define FAULT_RELAY_HIGH    HIGH
#define FAULT_RELAY_SAFE    HIGH

// ===========================================================================
//  DEFINICJE TYPÓW (muszą być PRZED pierwszą funkcją)
//  Arduino IDE automatycznie generuje prototypy funkcji. Jeśli typy
//  (enum/struct) są zadeklarowane niżej niż pierwszy nagłówek funkcji,
//  kompilator zgłasza błędy "does not name a type".
// ===========================================================================

// K2. Klasyfikacja sygnalu APS11450 (SignalClass)
enum SignalClass {
    SIG_LOW,        // poprawny LOW  (10-30% VPU)
    SIG_HIGH,       // poprawny HIGH (70-90% VPU)
    SIG_EXT_FAULT,  // usterka zewnetrzna (0-10% lub 30-70% VPU)
    SIG_INT_FAULT   // usterka wewnetrzna (90-100% VPU, VOUT = VPU)
};

// K3. Wynik warstwy sprzetowej (Sensor Manager)
struct SensorState {
    // Kontrakt wg Soft_Req_Spec_APS11450.md sekcja 2:
    bool low;           // aktywny HIGH na czujniku LOW
    bool high;          // aktywny HIGH na czujniku HIGH
    bool safety;        // aktywny HIGH na czujniku SAFETY
    bool lowFault;      // usterka (internal || external) czujnika LOW
    bool highFault;     // usterka czujnika HIGH
    bool safetyFault;   // usterka czujnika SAFETY
    // Rozszerzenie diagnostyczne - rozroznienie internal/external
    // potrzebne do kodow E10-E12 (internal) oraz E20-E22 (external):
    SignalClass lowClass;
    SignalClass highClass;
    SignalClass safetyClass;
};

// K6. Model poziomu
enum Level {
    LVL_UNKNOWN,
    LVL_EMPTY,
    LVL_LEVEL1,
    LVL_LEVEL2,
    LVL_LEVEL3,
    LVL_FAULT
};

// K6. Kody diagnostyczne
enum DiagCode {
    E00 = 0,    // brak bledu
    E10 = 10,   // Internal Fault: low
    E11 = 11,   // Internal Fault: high
    E12 = 12,   // Internal Fault: safe
    E20 = 20,   // External Fault: low
    E21 = 21,   // External Fault: high
    E22 = 22,   // External Fault: safe
    E30 = 30,   // kombinacja niedozwolona (niespojne stany)
    E31 = 31,   // przeskok poziomu
    E32 = 32,   // zbyt dlugi stan przejsciowy (timeout)
    E33 = 33,   // blad sekwencji
    E34 = 34    // utrata synchronizacji
};

// K7. Wynik resolvera poziomu
struct LevelResult {
    Level    level;   // aktualny (zatwierdzony) poziom systemu
    DiagCode code;    // kod diagnostyczny biezacego cyklu
};

// Klasyfikuje napiecie wyjscia (jako ulamek VPU = Vcc) do klasy sygnalu.
// Granice wg APS11450.md sekcja 6.
SignalClass classifySignal(float vFrac)
{
    if (vFrac < VFRAC_EXTLOW_MAX) return SIG_EXT_FAULT; // 0-10%
    if (vFrac < VFRAC_LOW_MAX)    return SIG_LOW;        // 10-30%
    if (vFrac < VFRAC_EXTMID_MAX) return SIG_EXT_FAULT;  // 30-70%
    if (vFrac < VFRAC_HIGH_MAX)   return SIG_HIGH;       // 70-90%
    return SIG_INT_FAULT;                                // 90-100%
}

// ===========================================================================
//  K4. Helpery sprzetowe (wzorzec z Detektor_APS1145.ino)
// ===========================================================================

// Pomiar napiecia zasilania VCC (bandgap 1.1V), wynik w mV.
long readVcc()
{
    ADMUX = _BV(REFS0) | _BV(MUX3) | _BV(MUX2) | _BV(MUX1);
    delay(2);
    ADCSRA |= _BV(ADSC);
    while (bit_is_set(ADCSRA, ADSC));
    long result = ADC;
    result = 1125300L / result;
    return result;
}

// Stabilny odczyt ADC: odrzucony pierwszy pomiar + krotka pauza.
int readADCStable(uint8_t pin)
{
    analogRead(pin);
    delayMicroseconds(20);
    return analogRead(pin);
}

// Konwersja wartosci ADC na napiecie [V] wzgledem zmierzonego Vcc.
float adcToVoltage(int adcValue)
{
    return (adcValue / ADC_MAX) * Vcc;
}

// ===========================================================================
//  K5. Sensor Manager - readSensors()
//  Odczytuje trzy czujniki i wypelnia SensorState. Nie interpretuje poziomu.
//  active  = SIG_HIGH
//  fault   = SIG_INT_FAULT || SIG_EXT_FAULT
//  Klasa jest wyznaczana z ulamka VPU = ADC / 1023 (referencja ADC = Vcc).
// ===========================================================================

// Odczyt pojedynczego czujnika -> klasa sygnalu.
SignalClass readSensorClass(uint8_t pin)
{
    float vFrac = readADCStable(pin) / ADC_MAX;
    return classifySignal(vFrac);
}

SensorState readSensors()
{
    SensorState s;

    s.lowClass    = readSensorClass(HALL_LOW_PIN);
    s.highClass   = readSensorClass(HALL_HIGH_PIN);
    s.safetyClass = readSensorClass(HALL_SAFE_PIN);

    s.low    = (s.lowClass    == SIG_HIGH);
    s.high   = (s.highClass   == SIG_HIGH);
    s.safety = (s.safetyClass == SIG_HIGH);

    s.lowFault    = (s.lowClass    == SIG_INT_FAULT || s.lowClass    == SIG_EXT_FAULT);
    s.highFault   = (s.highClass   == SIG_INT_FAULT || s.highClass   == SIG_EXT_FAULT);
    s.safetyFault = (s.safetyClass == SIG_INT_FAULT || s.safetyClass == SIG_EXT_FAULT);

    return s;
}

// ===========================================================================
//  K6. Model poziomu i helpery raw
// ===========================================================================

// Surowe bity raw = (low, high, safety), MSB = low.
// raw = (low<<2) | (high<<1) | safety.
uint8_t rawFromSensors(const SensorState &s)
{
    return (uint8_t)((s.low ? 4 : 0) | (s.high ? 2 : 0) | (s.safety ? 1 : 0));
}

// Czy kombinacja raw jest dozwolona (odpowiada realnemu poziomowi).
// Dozwolone: 000,100,110,111. Niedozwolone: 010,001,101,011 (sekcja 10 spec).
bool isValidRaw(uint8_t raw)
{
    return (raw == 0b000 || raw == 0b100 || raw == 0b110 || raw == 0b111);
}

// Mapuje dozwolony raw na poziom; dla niedozwolonego zwraca LVL_UNKNOWN.
Level levelFromRaw(uint8_t raw)
{
    switch (raw) {
        case 0b000: return LVL_EMPTY;
        case 0b100: return LVL_LEVEL1;
        case 0b110: return LVL_LEVEL2;
        case 0b111: return LVL_LEVEL3;
        default:    return LVL_UNKNOWN;
    }
}

// ===========================================================================
//  K7. Level Resolver - jedyny modul z pamiecia stanu
//  (Soft_Req_Spec sekcje 5,7,9,10). Zwraca poziom + kod diagnostyczny.
// ===========================================================================

// --- Stan wewnetrzny resolvera ---
Level         currentLevel   = LVL_UNKNOWN;  // zatwierdzony poziom
Level         candidateLevel = LVL_UNKNOWN;  // poziom oczekujacy na stabilizacje
unsigned long candidateSince = 0;            // millis() pojawienia sie kandydata
unsigned long transientSince = 0;            // millis() poczatku stanu niedozwolonego (0=brak)

// Indeks poziomu do oceny sasiedztwa (EMPTY=0..LEVEL3=3, inne = -1).
int levelIndex(Level lvl)
{
    switch (lvl) {
        case LVL_EMPTY:  return 0;
        case LVL_LEVEL1: return 1;
        case LVL_LEVEL2: return 2;
        case LVL_LEVEL3: return 3;
        default:         return -1;
    }
}

// Kod usterki sprzetowej: priorytet Internal (E10-E12) przed External (E20-E22).
DiagCode faultCode(const SensorState &s)
{
    if (s.lowClass    == SIG_INT_FAULT) return E10;
    if (s.highClass   == SIG_INT_FAULT) return E11;
    if (s.safetyClass == SIG_INT_FAULT) return E12;
    if (s.lowClass    == SIG_EXT_FAULT) return E20;
    if (s.highClass   == SIG_EXT_FAULT) return E21;
    if (s.safetyClass == SIG_EXT_FAULT) return E22;
    return E00;
}

// Ustawia stan poczatkowy resolvera (wywolywane po glosowaniu w setup).
void resolverInit(Level initial)
{
    currentLevel   = initial;
    candidateLevel = LVL_UNKNOWN;
    candidateSince = millis();
    transientSince = 0;
}

LevelResult resolveLevel(const SensorState &s)
{
    LevelResult r;
    unsigned long now = millis();

    // 1) Diagnostyka sprzetowa -> FAULT + Alarm (tabela przejsc: dowolny->FAULT).
    if (s.lowFault || s.highFault || s.safetyFault) {
        currentLevel   = LVL_FAULT;
        candidateLevel = LVL_UNKNOWN;
        candidateSince = now;
        transientSince = 0;
        r.level = LVL_FAULT;
        r.code  = faultCode(s);
        return r;
    }

    // Usterka ustapila: FAULT -> UNKNOWN (odzysk), dalej jak po restarcie.
    if (currentLevel == LVL_FAULT) {
        currentLevel   = LVL_UNKNOWN;
        candidateLevel = LVL_UNKNOWN;
        candidateSince = now;
        transientSince = 0;
    }

    uint8_t raw = rawFromSensors(s);

    // 2) Kombinacja niedozwolona -> trzymaj poprzedni poziom (sekcja 10).
    if (!isValidRaw(raw)) {
        if (transientSince == 0) transientSince = now;
        candidateLevel = LVL_UNKNOWN;         // niepewny stan przejsciowy
        r.level = currentLevel;
        r.code  = (now - transientSince >= TRANSIENT_TIMEOUT_MS) ? E32 : E30;
        return r;
    }

    // 3) Raw poprawny.
    transientSince = 0;
    Level observed = levelFromRaw(raw);

    // 3a) Zgodny z aktualnym poziomem -> stabilnie, bez zmiany.
    if (observed == currentLevel) {
        candidateLevel = LVL_UNKNOWN;
        r.level = currentLevel;
        r.code  = E00;
        return r;
    }

    // 3b) Nowy kandydat -> rozpocznij odliczanie stabilizacji.
    if (observed != candidateLevel) {
        candidateLevel = observed;
        candidateSince = now;
        r.level = currentLevel;
        r.code  = E00;
        return r;
    }

    // 3c) Kandydat utrzymuje sie, ale za krotko -> czekaj.
    if (now - candidateSince < STABLE_MS) {
        r.level = currentLevel;
        r.code  = E00;
        return r;
    }

    // 3d) Kandydat stabilny przez STABLE_MS -> zatwierdz.
    DiagCode code = E00;
    if (currentLevel == LVL_UNKNOWN) {
        // Inicjalizacja / odzysk (INIT_COMPLETE): przyjmij dowolny poprawny poziom.
        currentLevel = observed;
    } else {
        int diff = levelIndex(observed) - levelIndex(currentLevel);
        currentLevel = observed;                 // zatwierdzamy nowy poziom
        if (diff != 1 && diff != -1) code = E31;  // przeskok poziomu (nie-sasiedni)
    }
    candidateLevel = LVL_UNKNOWN;
    r.level = currentLevel;
    r.code  = code;
    return r;
}

// ===========================================================================
//  K8. Wirtualne elektrody (Soft_Req_Spec sekcja 4)
//  EMPTY=000, LEVEL1=100, LEVEL2=110, LEVEL3=111.
// ===========================================================================
void electrodesFromLevel(Level lvl, bool &e1, bool &e2, bool &e3)
{
    switch (lvl) {
        case LVL_LEVEL1: e1 = true;  e2 = false; e3 = false; break;
        case LVL_LEVEL2: e1 = true;  e2 = true;  e3 = false; break;
        case LVL_LEVEL3: e1 = true;  e2 = true;  e3 = true;  break;
        case LVL_EMPTY:                                       // 000
        default:         e1 = false; e2 = false; e3 = false; break;
    }
}

// ===========================================================================
//  K9. Relay Manager - mapuje elektrody E1-E3 na przekazniki R1-R3.
//  W stanie FAULT stosuje polityke bezpieczenstwa FAULT_RELAYS.
// ===========================================================================

// Steruje przekaznikami bezposrednio wg elektrod.
void applyElectrodes(bool e1, bool e2, bool e3)
{
    digitalWrite(RELAY_LOW_PIN,  e1 ? HIGH : LOW);  // R1 = E1
    digitalWrite(RELAY_HIGH_PIN, e2 ? HIGH : LOW);  // R2 = E2
    digitalWrite(RELAY_SAFE_PIN, e3 ? HIGH : LOW);  // R3 = E3
}

// Ustawia wyjscia na podstawie poziomu.
void applyLevel(Level lvl)
{
    if (lvl == LVL_FAULT) {
        // Polityka bezpieczenstwa - wszystkie przekazniki ON (stan alarmowy).
        digitalWrite(RELAY_LOW_PIN,  FAULT_RELAY_LOW);
        digitalWrite(RELAY_HIGH_PIN, FAULT_RELAY_HIGH);
        digitalWrite(RELAY_SAFE_PIN, FAULT_RELAY_SAFE);
        return;
    }
    if (lvl == LVL_UNKNOWN) {
        // Poziom nieustalony (init/odzysk) - utrzymaj poprzedni stan wyjsc.
        return;
    }
    bool e1, e2, e3;
    electrodesFromLevel(lvl, e1, e2, e3);
    applyElectrodes(e1, e2, e3);
}

// ===========================================================================
//  Helpery prezentacji (Serial / OLED)
// ===========================================================================

// Krotki symbol klasy sygnalu: L=LOW, H=HIGH, X=External, I=Internal.
char sigChar(SignalClass c)
{
    switch (c) {
        case SIG_LOW:       return 'L';
        case SIG_HIGH:      return 'H';
        case SIG_EXT_FAULT: return 'X';
        case SIG_INT_FAULT: return 'I';
        default:            return '?';
    }
}

// Nazwa poziomu do logu.
const char *levelName(Level lvl)
{
    switch (lvl) {
        case LVL_EMPTY:  return "EMPTY";
        case LVL_LEVEL1: return "LEVEL1";
        case LVL_LEVEL2: return "LEVEL2";
        case LVL_LEVEL3: return "LEVEL3";
        case LVL_FAULT:  return "FAULT";
        default:         return "UNKNOWN";
    }
}

// Formatuje kod diagnostyczny jako "Exx" (buf: min. 4 bajty).
void diagCodeStr(DiagCode code, char *buf)
{
    int v = (int)code;
    buf[0] = 'E';
    buf[1] = '0' + (v / 10) % 10;
    buf[2] = '0' + (v % 10);
    buf[3] = '\0';
}

// Indeks poziomu -> Level (odwrotnosc levelIndex dla EMPTY..LEVEL3).
Level indexToLevel(int idx)
{
    switch (idx) {
        case 1:  return LVL_LEVEL1;
        case 2:  return LVL_LEVEL2;
        case 3:  return LVL_LEVEL3;
        default: return LVL_EMPTY;
    }
}

unsigned long lastLogTime = 0;
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
void loop()
{
    wdt_reset();

    SensorState s   = readSensors();
    LevelResult res = resolveLevel(s);
    applyLevel(res.level);

    if (millis() - lastLogTime >= logInterval) {
        lastLogTime = millis();

        // Napiecia do wyswietlenia (odczyt diagnostyczny).
        float vLow  = adcToVoltage(readADCStable(HALL_LOW_PIN));
        float vHigh = adcToVoltage(readADCStable(HALL_HIGH_PIN));
        float vSafe = adcToVoltage(readADCStable(HALL_SAFE_PIN));

        bool e1, e2, e3;
        electrodesFromLevel(res.level, e1, e2, e3);

        char code[4];
        diagCodeStr(res.code, code);

        uint8_t raw = rawFromSensors(s);

        // --- Serial ---
        Serial.print(F("V(L/H/S): "));
        Serial.print(vLow, 2);  Serial.print('/');
        Serial.print(vHigh, 2); Serial.print('/');
        Serial.print(vSafe, 2);
        Serial.print(F(" | sig: "));
        Serial.print(sigChar(s.lowClass));
        Serial.print(sigChar(s.highClass));
        Serial.print(sigChar(s.safetyClass));
        Serial.print(F(" | raw: "));
        Serial.print((raw >> 2) & 1);
        Serial.print((raw >> 1) & 1);
        Serial.print(raw & 1);
        Serial.print(F(" | level: "));
        Serial.print(levelName(res.level));
        Serial.print(F(" | E: "));
        Serial.print(e1); Serial.print(e2); Serial.print(e3);
        Serial.print(F(" | code: "));
        Serial.println(code);

        // --- OLED ---
        display.clearDisplay();
        display.setTextSize(1);
        display.setCursor(0, 0);
        display.println(F("APS11450 Monitor"));
        display.println(F("----------------"));
        display.print(F("Level: "));
        display.println(levelName(res.level));
        display.print(F("E: "));
        display.print(e1); display.print(' ');
        display.print(e2); display.print(' ');
        display.println(e3);
        display.print(F("Sig: "));
        display.print(sigChar(s.lowClass));
        display.print(sigChar(s.highClass));
        display.println(sigChar(s.safetyClass));
        display.print(F("Code: "));
        display.println(code);
        display.display();
    }
}

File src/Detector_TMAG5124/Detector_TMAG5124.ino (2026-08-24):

#include <avr/wdt.h>
#include <Wire.h>
#include <Adafruit_GFX.h>
#include <Adafruit_SSD1306.h>

#define SCREEN_WIDTH 128
#define SCREEN_HEIGHT 64
#define OLED_RESET -1
#define SCREEN_ADDRESS 0x3C

Adafruit_SSD1306 display(SCREEN_WIDTH, SCREEN_HEIGHT, &Wire, OLED_RESET);

#define SENSOR_LOW_PIN        A3
#define SENSOR_HIGH_PIN       A6
#define SENSOR_SAFE_PIN       A7

#define RELAY_LOW_PIN        A0
#define RELAY_HIGH_PIN       A1
#define RELAY_SAFE_PIN       A2

#define ADC_MAX 1023.0

float Vcc = 0.0;

// Relay board is configured as active-low: ON = LOW, OFF/OPEN = HIGH.
const bool RELAY_ACTIVE = LOW;
const bool RELAY_OPEN = HIGH;

// Measured real-world values on this board:
// - no magnet: ~2.56..2.59 V
// - magnet present: ~0.68..0.72 V
// Hysteresis uses a midpoint window to avoid chattering around the transition.
const float MAGNET_DETECTED_V = 1.2;
const float MAGNET_RELEASED_V = 1.8;

// Fault detection thresholds: below 0.25 V = open circuit, above 4.2 V = overcurrent.
const float SENSOR_OPEN_V = 0.25;
const float SENSOR_OVER_CURRENT_V = 4.2;

unsigned long lastLogTime = 0;
const unsigned long logInterval = 500;

bool sensorLowState = false;
bool sensorHighState = false;
bool sensorSafeState = false;

enum SensorDiag {
    DIAG_OK,
    DIAG_OPEN,
    DIAG_OVER_CURRENT
};

const char* diagToString(SensorDiag diag)
{
    switch (diag)
    {
        case DIAG_OPEN:
            return "OPEN";
        case DIAG_OVER_CURRENT:
            return "OVR";
        case DIAG_OK:
        default:
            return "OK";
    }
}

long readVcc()
{
    ADMUX = _BV(REFS0) | _BV(MUX3) | _BV(MUX2) | _BV(MUX1);
    delay(2);
    ADCSRA |= _BV(ADSC);
    while (bit_is_set(ADCSRA, ADSC));
    long result = ADC;
    result = 1125300L / result;
    return result;
}

int readADCStable(uint8_t pin)
{
    uint32_t sum = 0;
    const uint8_t samples = 8;

    for (uint8_t i = 0; i < samples; i++)
    {
        analogRead(pin);
        delayMicroseconds(20);
        sum += analogRead(pin);
    }

    return (int)(sum / samples);
}

float adcToVoltage(int adcValue)
{
    return (adcValue / ADC_MAX) * Vcc;
}

bool applyHysteresis(float voltage, bool currentState)
{
    // Magnet present => lower voltage on the sense resistor.
    if (!currentState && voltage < MAGNET_DETECTED_V)
        return true;

    if (currentState && voltage > MAGNET_RELEASED_V)
        return false;

    return currentState;
}

bool isValidSensorVoltage(float voltage)
{
    return voltage >= SENSOR_OPEN_V && voltage <= SENSOR_OVER_CURRENT_V;
}

SensorDiag getSensorDiag(float voltage)
{
    if (voltage < SENSOR_OPEN_V)
        return DIAG_OPEN;

    if (voltage > SENSOR_OVER_CURRENT_V)
        return DIAG_OVER_CURRENT;

    return DIAG_OK;
}

// Clear fault state and keep the relay open if the input is invalid.
void updateRelayState(bool& sensorState, float voltage, SensorDiag diag)
{
    if (diag == DIAG_OPEN || diag == DIAG_OVER_CURRENT)
    {
        sensorState = false;
        return;
    }

    sensorState = applyHysteresis(voltage, sensorState);
}

// The board expects an active-low relay drive.
void setRelayState(uint8_t pin, bool active)
{
    digitalWrite(pin, active ? RELAY_ACTIVE : RELAY_OPEN);
}

const char* bitState(bool state)
{
    return state ? "1" : "0";
}

void setup()
{
    wdt_disable();

    Serial.begin(115200);

    pinMode(RELAY_LOW_PIN, OUTPUT);
    pinMode(RELAY_HIGH_PIN, OUTPUT);
    pinMode(RELAY_SAFE_PIN, OUTPUT);

    digitalWrite(RELAY_LOW_PIN, LOW);
    digitalWrite(RELAY_HIGH_PIN, LOW);
    digitalWrite(RELAY_SAFE_PIN, LOW);

    delay(100);

    if (!display.begin(SSD1306_SWITCHCAPVCC, SCREEN_ADDRESS)) {
        Serial.println(F("SSD1306 allocation failed"));
        for (;;);
    }

    display.clearDisplay();
    display.setTextSize(1);
    display.setTextColor(SSD1306_WHITE);
    display.setCursor(0, 0);
    display.println(F("TMAG5124 Init..."));
    display.display();
    delay(1000);

    Vcc = readVcc() / 1000.0;

    delay(100);

    float vLow  = adcToVoltage(readADCStable(SENSOR_LOW_PIN));
    float vHigh = adcToVoltage(readADCStable(SENSOR_HIGH_PIN));
    float vSafe = adcToVoltage(readADCStable(SENSOR_SAFE_PIN));

    sensorLowState  = false;
    sensorHighState = false;
    sensorSafeState = false;

    if (isValidSensorVoltage(vLow))
        sensorLowState = (vLow < MAGNET_DETECTED_V);
    if (isValidSensorVoltage(vHigh))
        sensorHighState = (vHigh < MAGNET_DETECTED_V);
    if (isValidSensorVoltage(vSafe))
        sensorSafeState = (vSafe < MAGNET_DETECTED_V);

    if (!isValidSensorVoltage(vLow))
        sensorLowState = false;
    if (!isValidSensorVoltage(vHigh))
        sensorHighState = false;
    if (!isValidSensorVoltage(vSafe))
        sensorSafeState = false;

    setRelayState(RELAY_LOW_PIN,  sensorLowState);
    setRelayState(RELAY_HIGH_PIN, sensorHighState);
    setRelayState(RELAY_SAFE_PIN, sensorSafeState);

    Serial.println("=== TMAG5124 SYSTEM START ===");
    Serial.print("Measured Vcc: ");
    Serial.print(Vcc, 3);
    Serial.println(" V");

    display.clearDisplay();
    display.setTextSize(1);
    display.setCursor(0, 0);
    display.println(F("=== TMAG5124 START ==="));
    display.print(F("Vcc: "));
    display.print(Vcc, 2);
    display.println(F(" V"));
    display.display();
    delay(2000);

    wdt_enable(WDTO_1S);
}
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

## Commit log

2026-02-06 input protection for io in pcb
2026-05-15 housing stl added
    [Pokrywa.stl, Pudlo.stl]
2026-07-14 doc reed switch update
2026-07-22 reed switch code added
2026-07-24 pump control algorith v1 and v2
2026-08-14 TMAG sensor code and doc added
2026-08-14 reed switch pdf added
2026-08-24 short fix oled sequence
    [Detector_TMAG5124.ino]
2026-08-24 calibration histeresis
2026-08-24 new voltage levels
